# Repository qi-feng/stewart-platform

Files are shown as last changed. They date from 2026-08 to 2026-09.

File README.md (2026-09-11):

# Servo Stewart Platform

A student-buildable, 3D-printed rotary Stewart platform using six hobby servos, an Arduino Nano ESP32, and a PCA9685 servo driver. The project is being developed as a motion-control and optical-alignment test bed, with optional TTL-controlled laser, joystick, camera, Raspberry Pi, and reinforcement-learning extensions.

This repository is a fork of [Nathan Ge's Stewart platform](https://github.com/nzge/stewart-platform). The mechanical design has been adapted for DS3225 servos and expanded with electronics holders, a laser mount, and camera/Pi mounting parts. This repo contains ChatGPT code and stl files; this README is also made with the help of ChatGPT.

> **Project status:** The current interactive firmware is suitable for serial control of the servos and the platform orientation, as well as manual motion demonstration. Its X/Y and roll/pitch commands are still preliminary - not yet geometrically decoupled six-degree-of-freedom inverse kinematics. The range of motion can be limited until the geometry, servo centers, directions, and mechanical limits have been calibrated. 

## Demonstration video

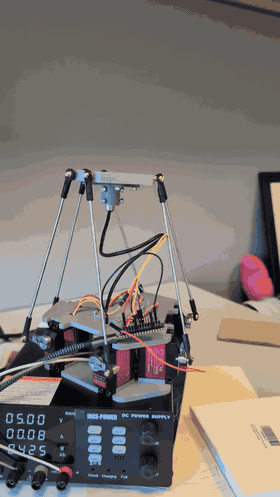
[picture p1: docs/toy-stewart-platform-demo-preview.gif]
Stewart platform demonstration


## Repository links

- [Revision 4 printable parts](https://github.com/qi-feng/stewart-platform/tree/main/cad/stewart-frame_rev4)
- [Arduino Stewart-platform controller](https://github.com/qi-feng/stewart-platform/blob/main/code/arduino-code/stewart_interactive_controller.ino)
- [Inverse-kinematics notebook](https://github.com/qi-feng/stewart-platform/blob/main/stewart_inverse-kinematics.ipynb)
- [Original Nathan Ge project](https://nzge.github.io/projects/stewart-platform.html)

## System overview

The Arduino Nano ESP32 sends I²C commands to the PCA9685. The PCA9685 generates six servo-control signals, while a separate regulated 5–6 V supply powers the servos. The joystick and USB/Wi-Fi console provide manual control. The Raspberry Pi, camera, and laser are optional and are not required for basic platform operation.

## Parts list

### Core electronics

| Qty | Part | Specification or example |
|---:|---|---|
| 6 | Positional digital servos | DS3225 (or similar), 25 kg class, 180° version—not continuous rotation |
| 1 | Microcontroller | [Arduino Nano ESP32 with headers, ABX00083](https://docs.arduino.cc/hardware/nano-esp32/) |
| 1 | Servo driver | [PCA9685 16-channel servo controller](https://www.amazon.com/dp/B07BRS249H) |
| 1 | Servo power supply | Regulated 5–6 V DC supply sized for the combined servo load; adjustable current limiting is useful during commissioning |
| 1 | Master power switch or emergency disconnect | Rated for the supply voltage and expected current |
| 1 | Inline fuse and holder | Select the fuse from the finished system's measured wiring and load requirements; do not automatically copy a 20 A value |
| 1 | Analog joystick with pushbutton | Two analog axes plus an active-low switch |
| 1 | USB-C data cable | For programming and initial Nano power |
| — | Logic and servo-power wiring | 20/22/24 AWG stranded wire or secure pre-crimped connectors |

### Mechanical parts

| Qty | Part | Specification or notes |
|---:|---|---|
| 6 | Aluminum clamping servo horns | 25T spline; approximately 25 mm servo-axis-to-ball-center radius in this build |
| 6 | M3 threaded linkage rods | Cut or adjust to the measured platform geometry |
| 12 | M3 ball-joint rod ends | Two per linkage; RC steering-linkage style |
| 12 | M3 jam nuts | One at each rod end to lock the adjusted linkage length |
| As needed | M3/M4 screws, washers, and nuts | Securing electronics, linkage hardware, and printed parts |
| As needed | M3/M4 heat-set inserts | For printed parts to mount the boards or the linkage rods |
| 1 set | 3D-printed structural parts | Base, base cover, upper platform/adapter, servo links, controller holder, and cover |
| 1 | Filament | PLA is suitable for initial builds; PETG can be used where greater toughness or heat resistance is useful |

All six completed linkages should begin with the same effective ball-center-to-ball-center length. The current prototype measurement is approximately **154 mm**, but builders must measure their own printed geometry rather than treating that value as universal.

### Optional optical and vision system

| Qty | Part | Specification or example |
|---:|---|---|
| 1 | TTL-controlled dot laser | 10 mm diameter × 40 mm length module used by this prototype |
| 1 | Printed laser mounts | Laser holder, camera case, camera stand, and Pi tray from the CAD directories |
| 1 | Camera | Arducam OV5647 5 MP camera with a Raspberry Pi or Xiao eps32s3-sense camera module or similar |
| 1 | Beam stop/enclosure | Non-reflective, mechanically secured, and appropriate for the selected laser class |

The laser and vision hardware are not needed for the initial servo build. Add them only after the platform homes reliably and its mechanical limits have been established.

## Wiring

Arduino Nano ESP32 to PCA9685 wiring

| Source pin | PCA9685 pin |
|---|---|
| Nano **3V3** | **VCC** |
| Nano **GND** | Logic-header **GND** |
| Nano **A4 / D21 / GPIO11** | **SDA** |
| Nano **A5 / D22 / GPIO12** | **SCL** |
| Servo supply **positive** | Screw-terminal **V+** |
| Servo supply **negative / 0 V** | Screw-terminal **GND** |
| Servo 0 three-wire plug | **CH0:** PWM/S, V+, GND |
| Servo 1 three-wire plug | **CH1:** PWM/S, V+, GND |
| Servo 2 three-wire plug | **CH2:** PWM/S, V+, GND |
| Servo 3 three-wire plug | **CH3:** PWM/S, V+, GND |
| Servo 4 three-wire plug | **CH4:** PWM/S, V+, GND |
| Servo 5 three-wire plug | **CH5:** PWM/S, V+, GND |
| PCA9685 **OE** | Leave unconnected for the basic build |

For each servo plug, connect its signal lead—usually orange, yellow, or white—to `PWM/S`; red to `V+`; and brown or black to `GND`. Follow the labels printed on the PCA9685 rather than assuming the physical row order is identical on every clone.

### Joystick wiring

| Joystick pin | Current project connection |
|---|---|
| VCC | PCA9685 **VCC** header—the same 3.3 V logic rail as Nano **3V3** |
| GND | PCA9685 logic-header **GND**—the common system ground |
| VRx | Nano **A0 / D17 / GPIO1** |
| VRy | Nano **A1 / D18 / GPIO2** |
| SW | Nano **D2 / GPIO5** |

### Current Quarton TTL-laser wiring

| Laser connection | Current project connection |
|---|---|
| Power / V+ | PCA9685 **V+** rail, supplied by the regulated **5 V** servo supply |
| Ground | PCA9685 **GND** / common system ground |
| TTL / EN | Nano **D7 / GPIO10** |

The sketch drives D7 **HIGH** to turn the laser on and **LOW** to turn it off. D7 is only the TTL control signal; it does not power the laser. This mapping is for the prototype's [Quarton VLM-520-61](https://www.quarton.com/green-circular-dot-laser-module-with-ttl-modulation-function-vlm-520-61-series.html) or [VLM-635-61](https://www.quarton.com/red-circular-dot-laser-module-with-ttl-modulation-function-vlm-635-61-series.html), which accept 3–6 V DC power. Verify the manufacturer's pinout rather than relying on wire color, especially when substituting a different module.

### Critical power rules

- `VCC` and `V+` are different. PCA9685 `VCC` receives 3.3 V logic power; `V+` receives the separate 5–6 V servo supply.
- Never power the six servos from the Nano's `3V3`, `VUSB`, or `VIN` pins.
- The Nano, PCA9685, servo supply, joystick, and optional laser-control circuit must share ground.
- Switch servo power off before changing wiring or installing servo horns.
- A breadboard may be used for low-current logic signals, but not for distributing servo power.

## Software setup

1. Install the [Arduino IDE](https://www.arduino.cc/en/software).
2. Install **Arduino ESP32 Boards by Arduino** using Boards Manager.
3. Select **Arduino Nano ESP32**.
4. Install **Adafruit PWM Servo Driver Library** using Library Manager.
5. Open the [Stewart-platform sketch](https://github.com/qi-feng/stewart-platform/blob/main/code/arduino-code/stewart_interactive_controller.ino).
6. Confirm the configured pins, servo directions, servo centers, and pulse limits before applying servo power.
7. Upload through USB-C and open Serial Monitor at **115200 baud**.

If the Wi-Fi-console version of the sketch is used, register the Nano's Wi-Fi MAC address, enter credentials locally without committing them to Git, and connect to the reported address with:

```bash
nc NANO_IP_ADDRESS 2323
```

## First power-on

1. Leave the servo horns disconnected from the linkages.
2. Confirm all six servos are positional 180° models.
3. Power the Nano over USB and verify that the PCA9685 responds at I²C address `0x40`.
4. Set the external servo supply to 5 V and a conservative current limit.
5. Connect and center one servo at a time.
6. Install each 25T horn at its intended neutral orientation while the servo is commanded to center.
7. Disconnect servo power and assemble the linkages.
8. Reapply power with one hand ready at the master disconnect.
9. Test HOME and small roll/pitch commands before selecting larger ranges or running the demonstration.

## Controls

The exact controls depend on the sketch revision. The current interactive development controller uses:

| Input | Action |
|---|---|
| Joystick X/Y | Accumulated roll and pitch control |
| Short joystick click | Toggle laser |
| Hold joystick button for 1 second | Smooth return to HOME |
| `h` | Return to HOME |
| `s` | Report current pulse-space pose and limits |
| `k` | Toggle laser |
| `?` | Print the complete command menu |

## Calibration and limitations

The current control values are PWM pulse offsets in microseconds; they are not millimeters or degrees. Before implementing true Cartesian motion, measure and record:

- Six base servo-axis coordinates and horn-rotation-axis directions
- Six upper-platform ball-joint coordinates
- Servo-axis-to-ball-center horn radius
- Effective ball-center-to-ball-center length of every linkage
- Individual servo direction, center pulse, minimum pulse, maximum pulse, and pulse-to-angle response
- Mechanical ball-joint and collision limits throughout the intended workspace

True inverse kinematics must solve each rotary horn angle from the requested platform translation and rotation. Until that solver is calibrated, X/Y motions may contain tilt and roll/pitch motions may contain translation.

## Laser safety

- Use the lowest-power visible laser that meets the experiment's needs.
- Enclose the beam path and terminate it with a fixed, non-reflective beam stop.
- Keep the beam below eye level and remove reflective objects from the enclosure.
- Turn the laser off during assembly, adjustment, and student access.
- Follow the institution's laser-safety rules and obtain approval from the responsible laboratory-safety office before classroom operation.

## Attribution and licensing

The starting mechanical design and repository structure came from [Nathan Ge's Stewart-platform project](https://github.com/nzge/stewart-platform). This fork contains subsequent experimental modifications and generated CAD/code artifacts.

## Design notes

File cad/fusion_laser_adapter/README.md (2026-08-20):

# Stewart-platform laser adapter generator

This Fusion 360 script modifies a selected solid copy of
`stewart-platform_adapter` and leaves the source assembly unchanged.

It creates:

- a 10.6 mm central laser passage;
- a 14 mm underside cable-relief pocket;
- a 30 mm OD × 4 mm reinforcing boss;
- a separate 10.4 mm-bore split collar for a 10 mm laser module.

## Run in Fusion

1. Open `stewart_assy.STEP` in Fusion's Design workspace.
2. Open **Utilities → Add-Ins → Scripts and Add-Ins**.
3. Select the **Scripts** tab and click the green **+** beside *My Scripts*.
4. Select the `fusion_laser_adapter` folder itself, not an individual `.py` file.
5. Run `fusion_laser_adapter`.
6. When prompted, select the solid body for `stewart-platform_adapter`.
7. Hide the original assembly and inspect the two new components.

The clamp is a first-fit collar intended for a small hose clamp or zip tie. Do
not print the full adapter until the center cut, rib reinforcement, cable relief,
and exact laser fit have been inspected in Fusion.

Fusion uses centimetres internally in its API; all user-facing dimensions above
are millimetres.

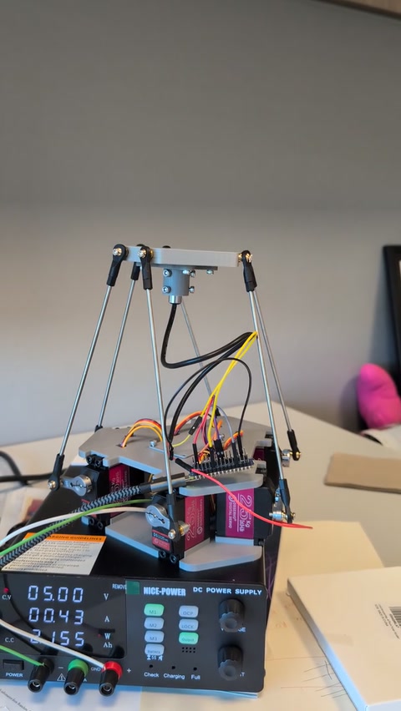
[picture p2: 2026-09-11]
docs/toy-stewart-platform-demo-poster.jpg

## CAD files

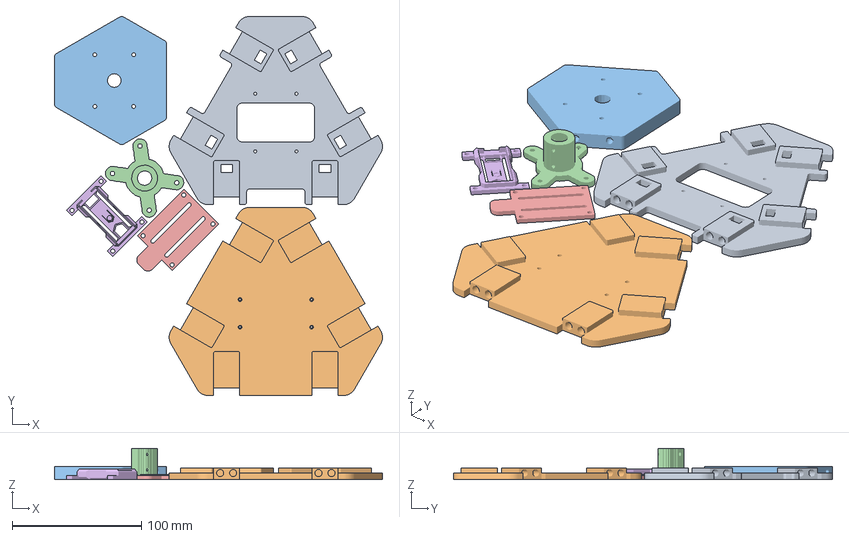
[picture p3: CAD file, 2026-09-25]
cad/stewart-frame_rev4/Stewart Platform.3mf
253.5 x 293.0 x 24.0 mm
base-cover_raised.STL
base_raised.STL
stewart-platform_adapter_laser_hole_centered.stl
laser_holder_10mm_six_screw_finder_40x30.stl
proto-board_nano-esp32_thick_slots_m3_usbc_support.stl
AN_top_cover_nano_esp32_m3_supported_bottom_mount_usb_flush.stl

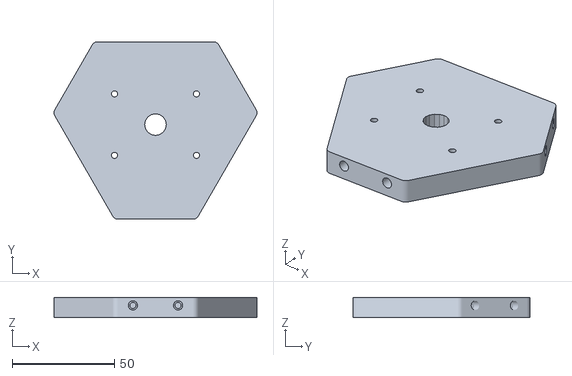
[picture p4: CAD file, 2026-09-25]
cad/stewart-frame_rev4/stewart-platform_adapter_laser_hole_centered.stl
99.1 x 86.6 x 10.0

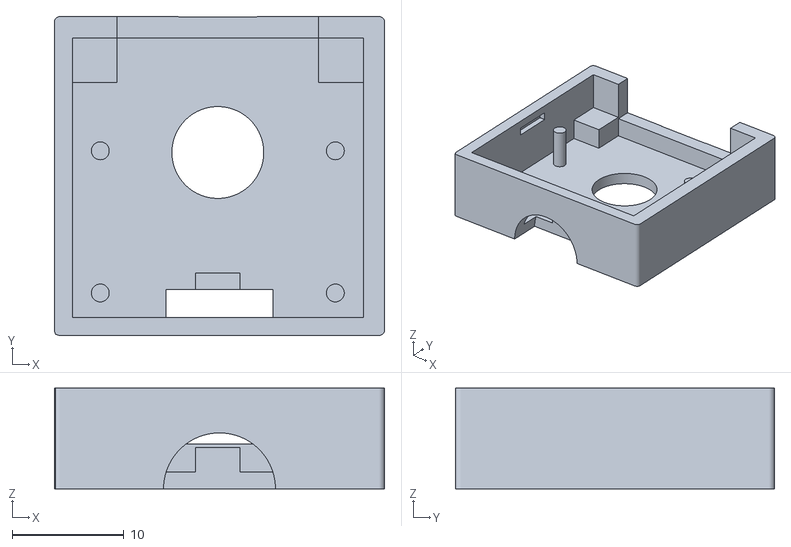
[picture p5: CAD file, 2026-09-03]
cad/stewart-frame_rev4/Arducam_OV5647_front_noear_opposite_pry_notch.stl
29.5 x 28.5 x 9.00

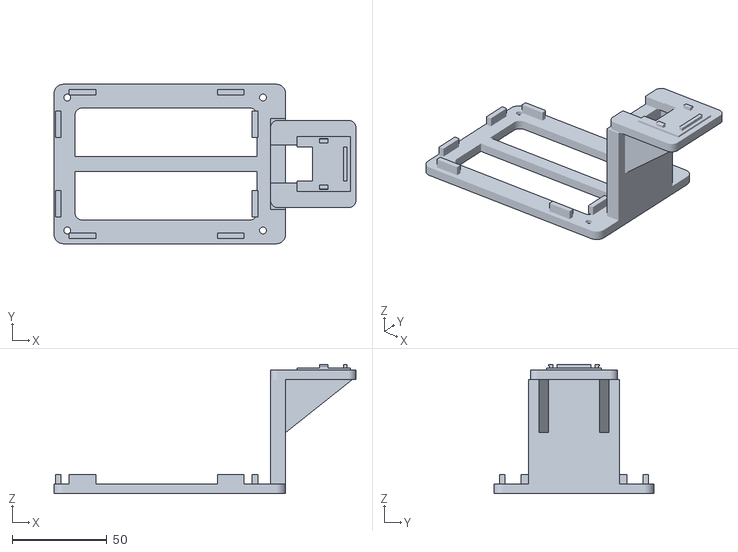
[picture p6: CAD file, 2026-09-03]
cad/stewart-frame_rev4/pi5_ov5647_split_02_pi_tray_camera_tower.stl
159.0 x 84.0 x 68.1

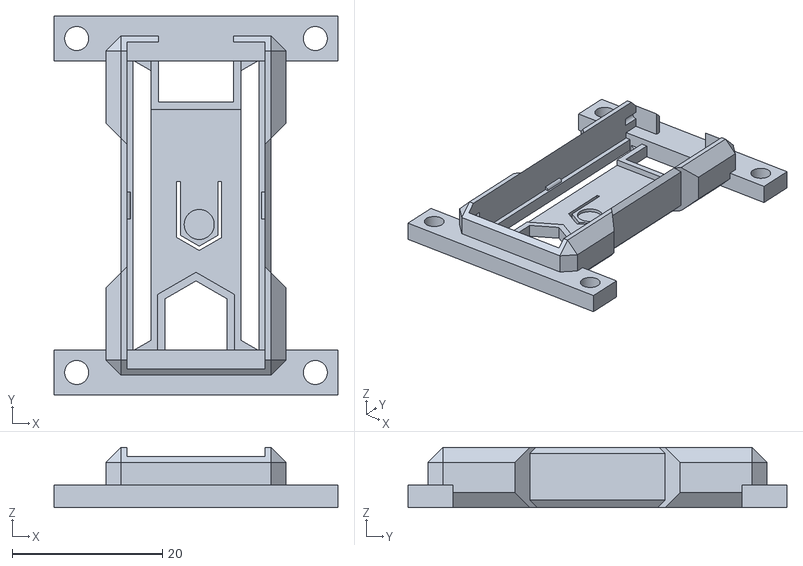
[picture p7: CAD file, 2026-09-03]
cad/stewart-frame_rev4/AN_top_cover_nano_esp32_m3_supported_bottom_mount_usb_flush.stl
37.8 x 50.5 x 8.00

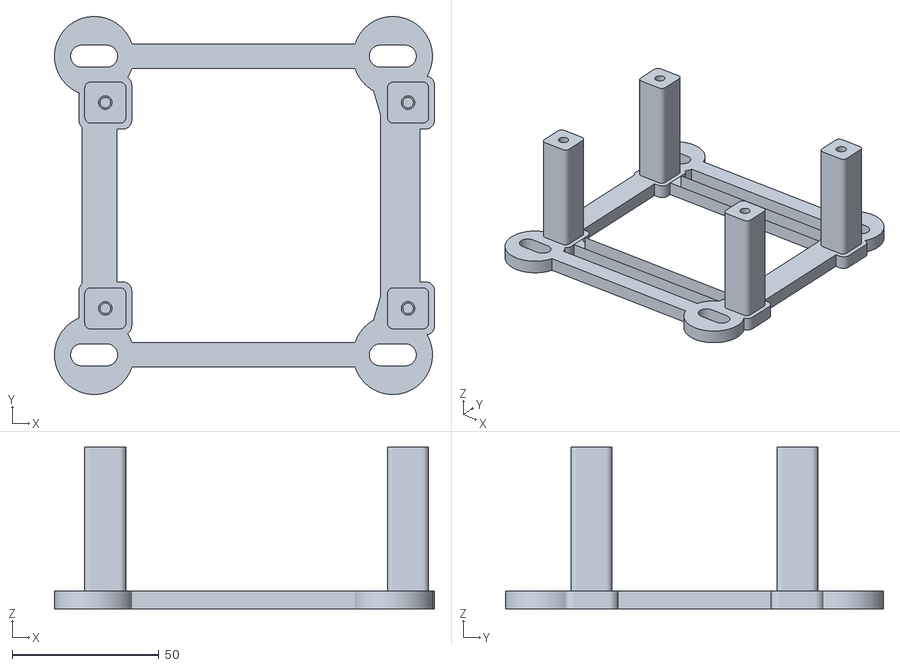
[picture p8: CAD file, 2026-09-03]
cad/stewart-frame_rev4/pi5_ov5647_split_01_optical_base_legs.stl
129.3 x 128.6 x 55.0

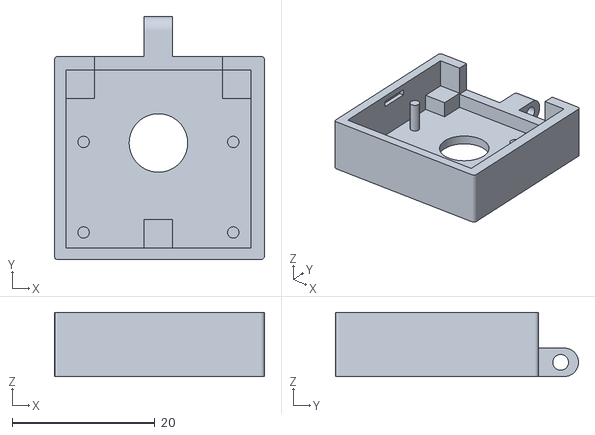
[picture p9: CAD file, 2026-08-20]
cad/stewart-frame_rev4/Arducam_OV5647_front-onepin.stl
29.5 x 34.1 x 9.00

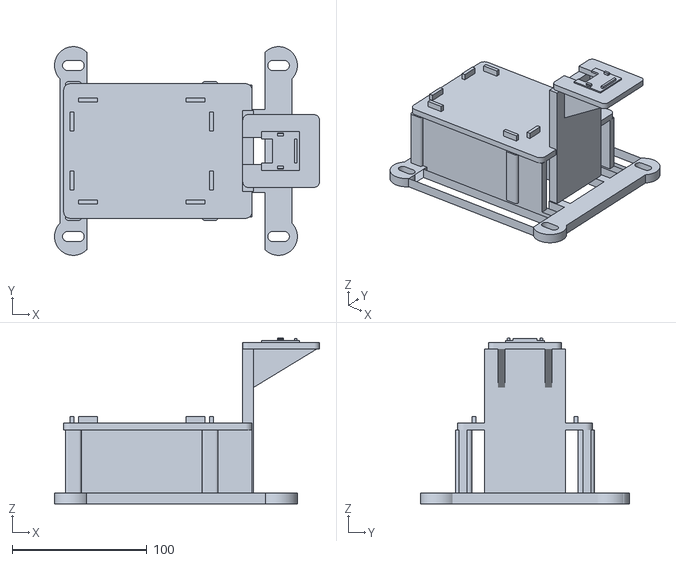
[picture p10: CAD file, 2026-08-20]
cad/stewart-frame_rev4/pi5_60mm_ov5647_120mm_optical_stand_back_ribbon_slot.stl
196.8 x 155.0 x 123.1

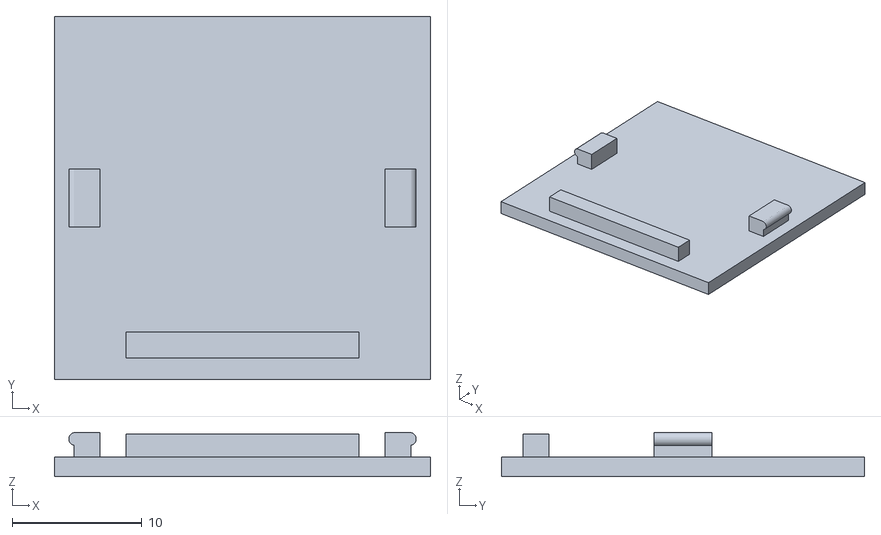
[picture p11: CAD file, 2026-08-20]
cad/stewart-frame_rev4/Arducam_OV5647_back.stl
29.0 x 28.0 x 3.40

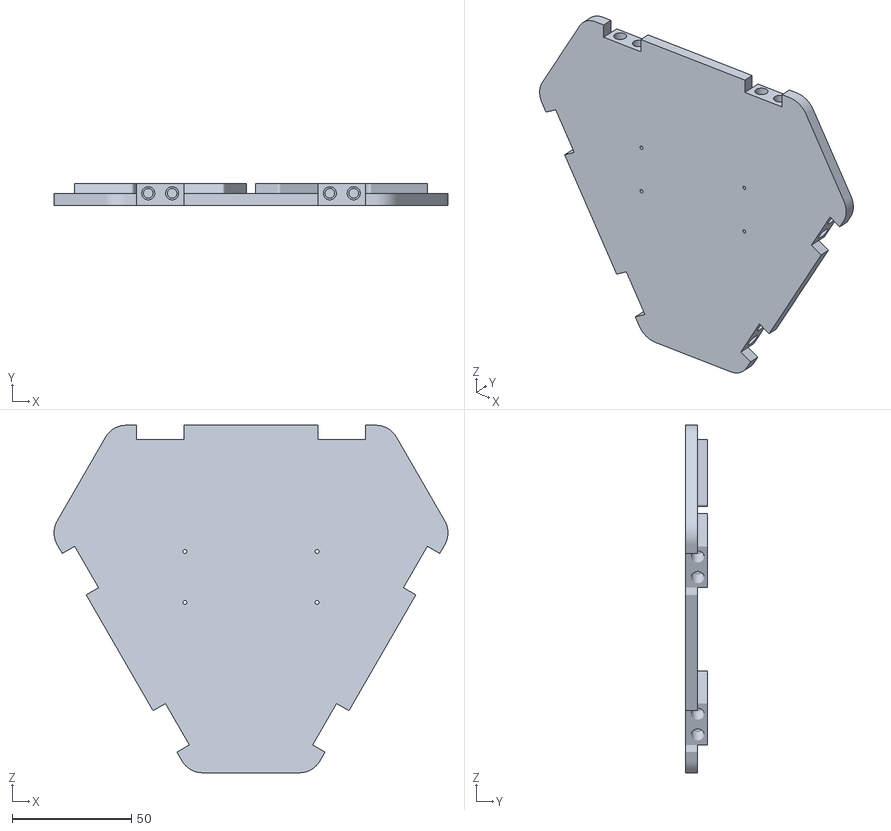
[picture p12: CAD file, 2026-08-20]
cad/stewart-frame_rev4/base_raised.STL
164.9 x 9.00 x 145.5

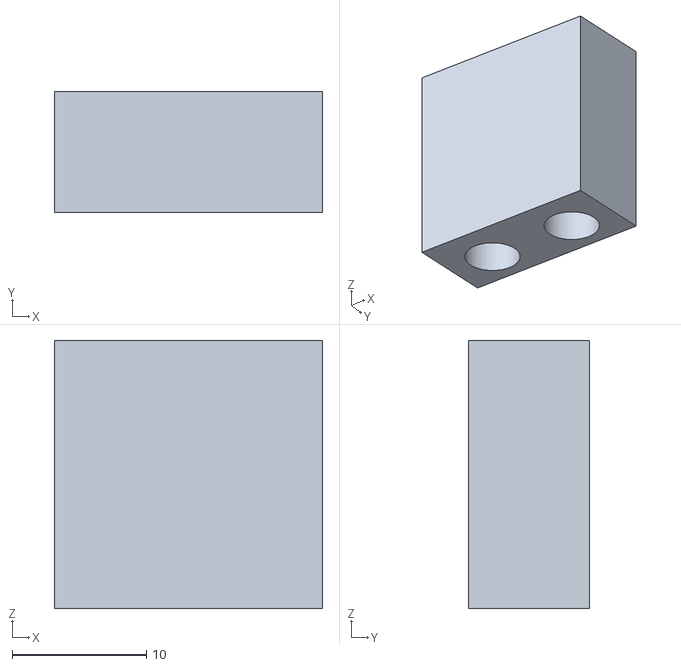
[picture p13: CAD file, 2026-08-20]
cad/stewart-frame_rev4/m4 heat insert test.STL
20.0 x 9.00 x 20.0

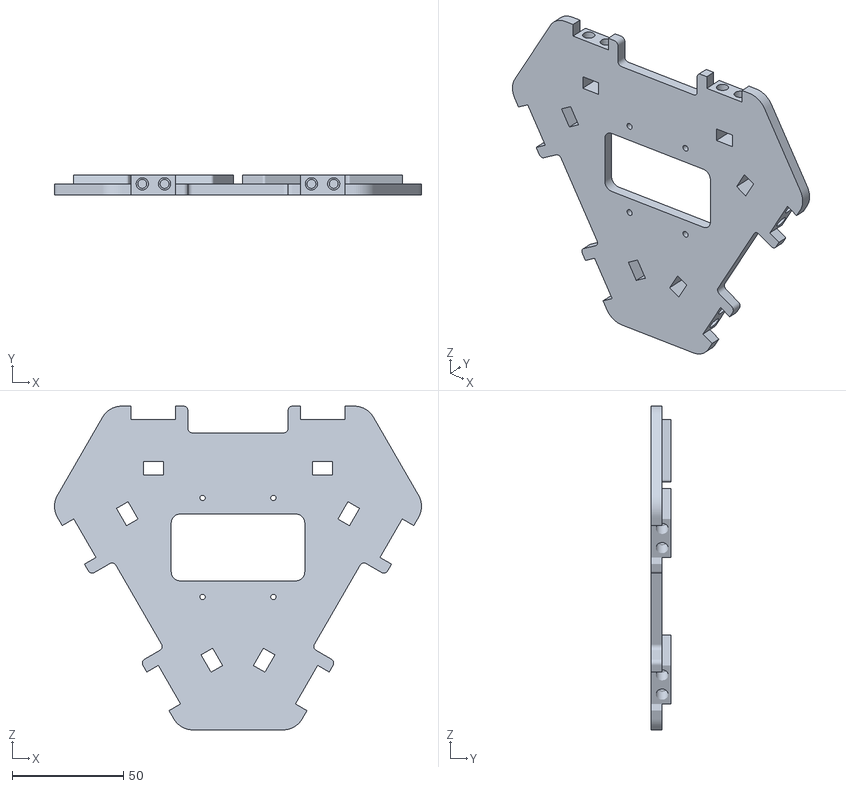
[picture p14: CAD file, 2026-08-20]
cad/stewart-frame_rev4/base-cover_raised.STL
164.9 x 9.00 x 145.5

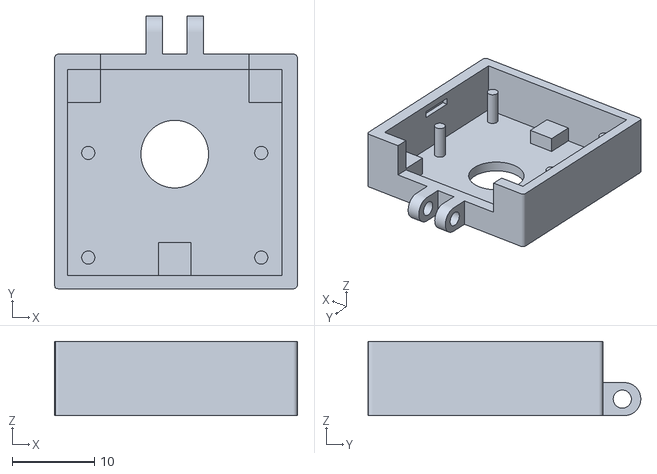
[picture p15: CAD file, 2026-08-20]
cad/stewart-frame_rev4/Arducam_OV5647_front.stl
29.5 x 33.1 x 9.00

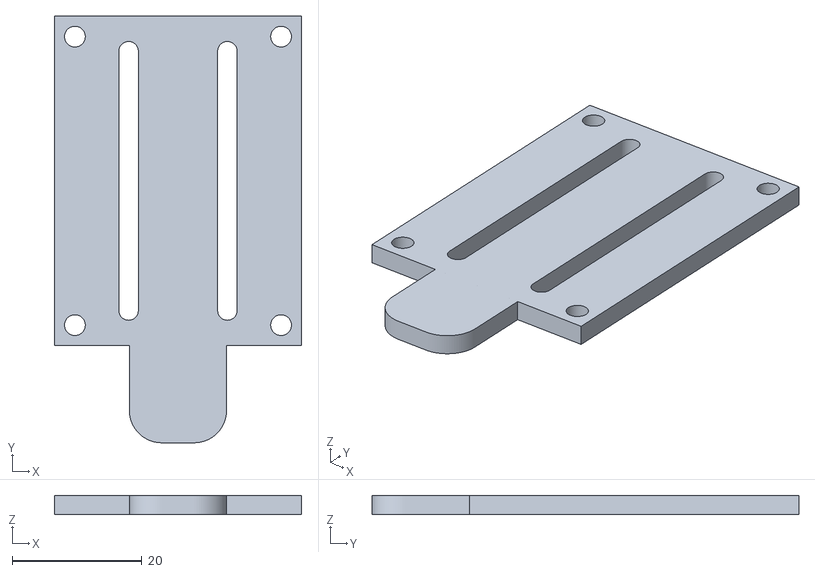
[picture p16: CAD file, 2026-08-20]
cad/stewart-frame_rev4/proto-board_nano-esp32_thick_slots_m3_usbc_support.stl
38.1 x 65.8 x 3.00

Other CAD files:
cad/stewart-frame_rev4/stewart-platform_adapter.STL
cad/stewart-frame_rev4/AN_top_cover_nano_esp32_m3_supported_bottom_mount.stl
cad/stewart-frame_rev4/laser_holder_10mm_six_screw_finder_40x30.stl
cad/stewart-frame_rev3/standoff.stl
cad/stewart-frame_rev3/AN_top_cover_nano_esp32_m3_mounting_legs.stl
cad/stewart-frame_rev3/AN_top_cover_nano_esp32_m3_supported_bottom_mount.stl
cad/stewart-frame_rev3/AN_top_cover_nano_esp32_m3_supported_top_mount.stl
cad/stewart-frame_rev3/C_Mount_Camera_Case_Back.stl
cad/stewart-frame_rev3/C_Mount_Camera_Case_Back_OV5647_4pin_1p35mm.stl
cad/stewart-frame_rev3/C_Mount_Camera_Case_Front.stl
cad/stewart-frame_rev3/C_Mount_Camera_Case_Front_Revison_A.stl
cad/stewart-frame_rev3/MORS.24.001.02 _ AN Top cover.stl
cad/stewart-frame_rev3/laser_holder_10mm_flanged_split.stl
cad/stewart-frame_rev3/laser_holder_10mm_m3_pinch_3point_adjustable_40x30.stl
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

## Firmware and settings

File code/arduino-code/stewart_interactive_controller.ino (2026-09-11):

// This sketch is written with the help of ChatGPT

#include <Wire.h>
#include <Adafruit_PWMServoDriver.h>
#include <math.h>
#include <WiFi.h>

Adafruit_PWMServoDriver pca9685(0x40);

constexpr uint8_t SERVO_COUNT = 6;
constexpr uint8_t LASER_PIN = D7;
constexpr uint8_t JOYSTICK_X_PIN = A0;
constexpr uint8_t JOYSTICK_Y_PIN = A1;
constexpr uint8_t JOYSTICK_BUTTON_PIN = D2;
constexpr float PCA_FREQUENCY = 50.0f;
constexpr unsigned long MOVE_MS = 180;    // Smooth response time per key press

// Joystick tuning for the Nano ESP32's 12-bit ADC (nominally 0-4095).
// Holding the stick farther from center produces faster accumulated motion.
constexpr int JOYSTICK_ADC_MAX = 4095;
constexpr int JOYSTICK_DEAD_ZONE = 180;
constexpr float JOYSTICK_MAX_RATE_US_PER_SECOND = 300.0f;
constexpr unsigned long JOYSTICK_UPDATE_MS = 40;
constexpr unsigned long BUTTON_DEBOUNCE_MS = 35;
constexpr unsigned long BUTTON_HOME_HOLD_MS = 1000;
constexpr unsigned long JOYSTICK_HOME_MOVE_MS = 600;
constexpr uint16_t WIFI_CONSOLE_PORT = 2323;
constexpr unsigned long WIFI_RETRY_MS = 15000;

// Replace only the password value before uploading. Keeping the Wi-Fi
// connection in this main sketch makes it reconnect after every restart.
const char* WIFI_SSID = "ULink";
const char* WIFI_PASSWORD = "xxxx";

WiFiServer consoleServer(WIFI_CONSOLE_PORT);
WiFiClient wifiConsole;
bool wifiServerStarted = false;
unsigned long lastWiFiAttemptMs = 0;

// Send status text to USB Serial and to the connected wireless console.
class TeeConsole : public Print {
 public:
  size_t write(uint8_t value) override {
    size_t written = Serial.write(value);
    if (wifiConsole && wifiConsole.connected()) {
      wifiConsole.write(value);
    }
    return written;
  }

  size_t write(const uint8_t* buffer, size_t size) override {
    size_t written = Serial.write(buffer, size);
    if (wifiConsole && wifiConsole.connected()) {
      wifiConsole.write(buffer, size);
    }
    return written;
  }
};

TeeConsole Console;

// Change either flag if an axis moves opposite to the direction you prefer.
constexpr bool REVERSE_JOYSTICK_ROLL = false;
constexpr bool REVERSE_JOYSTICK_PITCH = true;

// Runtime-adjustable control settings. Start in step gear 5 and range gear 8.
// Keys 1-5 and 6-9 can still change these settings after startup.
float stepUs = 100.0f;
float poseLimitUs = 700.0f;
float combinedLimitUs = 950.0f;

const uint8_t servoChannel[SERVO_COUNT] = {0, 1, 2, 3, 4, 5};

// Change an entry if that installed servo moves opposite to the desired motion.
int8_t servoDirection[SERVO_COUNT] = {+1, -1, +1, -1, +1, -1};

uint16_t servoCenterUs[SERVO_COUNT] = {1500, 1500, 1500, 1500, 1500, 1500};
// Wide hard limits for a nominal 500-2500 us / 180-degree DS3225. The 50 us
// endpoint margin avoids deliberately driving against the mechanical stops.
uint16_t servoMinUs[SERVO_COUNT] = {550, 550, 550, 550, 550, 550};
uint16_t servoMaxUs[SERVO_COUNT] = {2450, 2450, 2450, 2450, 2450, 2450};

float currentPulseUs[SERVO_COUNT] = {1500, 1500, 1500, 1500, 1500, 1500};

// Servo positions viewed from above:
//
//                 BACK
//              3       4
//          2               5
//              1       0
//                 FRONT
const float servoX[SERVO_COUNT] = {0.5, -0.5, -1.0, -0.5, 0.5, 1.0};
const float servoY[SERVO_COUNT] = {-0.866, -0.866, 0.0, 0.866, 0.866, 0.0};

// Preliminary alternating-leg yaw pattern. This is only a diagnostic until
// the real base/platform joint coordinates and horn geometry are calibrated.
const float servoYaw[SERVO_COUNT] = {1.0, -1.0, 1.0, -1.0, 1.0, -1.0};

// Persistent "game" controls. Repeated key presses accumulate here.
float poseX = 0;
float poseY = 0;
float poseZ = 0;
float poseRoll = 0;
float posePitch = 0;
float poseYaw = 0;
bool laserIsOn = false;

int joystickCenterX = JOYSTICK_ADC_MAX / 2;
int joystickCenterY = JOYSTICK_ADC_MAX / 2;
unsigned long lastJoystickUpdateMs = 0;
bool lastButtonReading = HIGH;
bool stableButtonState = HIGH;
unsigned long lastButtonChangeMs = 0;
unsigned long buttonPressedMs = 0;
bool longPressHandled = false;
bool homeRequested = false;

void updateJoystickButton();
void homePlatform(unsigned long durationMs = MOVE_MS);
void handleCommand(char command);
void printPose();
void printMenu();

void beginWiFiAttempt() {
  WiFi.begin(WIFI_SSID, WIFI_PASSWORD);
  lastWiFiAttemptMs = millis();
  Console.println("Connecting to Wi-Fi in background...");
}

void startWiFiConsole() {
  WiFi.mode(WIFI_STA);
  WiFi.setSleep(false);
  Console.print("Nano ESP32 Wi-Fi MAC: ");
  Console.println(WiFi.macAddress());
  beginWiFiAttempt();
}

void serviceWiFiConsole() {
  if (WiFi.status() != WL_CONNECTED) {
    if (wifiConsole) wifiConsole.stop();
    wifiServerStarted = false;

    if (millis() - lastWiFiAttemptMs >= WIFI_RETRY_MS) {
      WiFi.disconnect();
      beginWiFiAttempt();
    }
    return;
  }

  if (!wifiServerStarted) {
    consoleServer.begin();
    wifiServerStarted = true;
    Console.print("Wi-Fi console ready at ");
    Console.print(WiFi.localIP());
    Console.print(":");
    Console.println(WIFI_CONSOLE_PORT);
  }

  if (!wifiConsole || !wifiConsole.connected()) {
    WiFiClient newClient = consoleServer.available();
    if (newClient) {
      wifiConsole.stop();
      wifiConsole = newClient;
      wifiConsole.setNoDelay(true);
      Console.println("Wireless console connected.");
      printPose();
      printMenu();
    }
  }

  while (wifiConsole && wifiConsole.connected() && wifiConsole.available()) {
    handleCommand((char)wifiConsole.read());
  }
}

void setLaser(bool turnOn) {
  laserIsOn = turnOn;
  digitalWrite(LASER_PIN, laserIsOn ? HIGH : LOW);
  Console.print("Laser: ");
  Console.println(laserIsOn ? "ON" : "OFF");
}

void toggleLaser() {
  setLaser(!laserIsOn);
}

float clampValue(float value, float low, float high) {
  if (value < low) return low;
  if (value > high) return high;
  return value;
}

uint16_t constrainPulse(uint8_t servo, float pulseUs) {
  return (uint16_t)round(clampValue(pulseUs, servoMinUs[servo], servoMaxUs[servo]));
}

void writeServoPulse(uint8_t servo, float pulseUs) {
  uint16_t safePulse = constrainPulse(servo, pulseUs);
  pca9685.writeMicroseconds(servoChannel[servo], safePulse);
  currentPulseUs[servo] = safePulse;
}

void moveToLogicalOffsets(const float requested[SERVO_COUNT], unsigned long durationMs) {
  float startPulse[SERVO_COUNT];
  float endPulse[SERVO_COUNT];
  float largest = 0;

  for (uint8_t i = 0; i < SERVO_COUNT; i++) {
    largest = max(largest, fabs(requested[i]));
  }

  // Preserve the requested shape while scaling it into the safe envelope.
  float scale = largest > combinedLimitUs ? combinedLimitUs / largest : 1.0f;

  for (uint8_t i = 0; i < SERVO_COUNT; i++) {
    startPulse[i] = currentPulseUs[i];
    float logicalOffset = requested[i] * scale;
    endPulse[i] = servoCenterUs[i] + servoDirection[i] * logicalOffset;
  }

  constexpr unsigned long UPDATE_MS = 20;
  unsigned long steps = max(1UL, durationMs / UPDATE_MS);

  for (unsigned long step = 1; step <= steps; step++) {
    float fraction = (float)step / (float)steps;
    float smooth = fraction * fraction * (3.0f - 2.0f * fraction);

    for (uint8_t servo = 0; servo < SERVO_COUNT; servo++) {
      float pulse = startPulse[servo] + (endPulse[servo] - startPulse[servo]) * smooth;
      writeServoPulse(servo, pulse);
    }
    // The older motion code is blocking, so explicitly service the click here.
    updateJoystickButton();
    delay(UPDATE_MS);
  }
}

void applyPose(unsigned long durationMs = MOVE_MS) {
  float offsets[SERVO_COUNT];

  for (uint8_t i = 0; i < SERVO_COUNT; i++) {
    // X/Y are diagnostic sway controls, not true Cartesian translations.
    // Roll/pitch use the same simple geometric weighting from the test sketch.
    offsets[i] = poseZ
               + poseX * servoX[i]
               + poseY * servoY[i]
               + poseRoll * servoX[i]
               + posePitch * servoY[i]
               + poseYaw * servoYaw[i];
  }

  moveToLogicalOffsets(offsets, durationMs);
}

void calibrateJoystickCenter() {
  constexpr uint8_t SAMPLE_COUNT = 32;
  long sumX = 0;
  long sumY = 0;

  Console.println("Release joystick and keep it centered: calibrating...");
  delay(300);
  for (uint8_t sample = 0; sample < SAMPLE_COUNT; sample++) {
    sumX += analogRead(JOYSTICK_X_PIN);
    sumY += analogRead(JOYSTICK_Y_PIN);
    delay(5);
  }

  joystickCenterX = sumX / SAMPLE_COUNT;
  joystickCenterY = sumY / SAMPLE_COUNT;
  lastJoystickUpdateMs = millis();

  Console.print("Joystick center: X=");
  Console.print(joystickCenterX);
  Console.print(" Y=");
  Console.println(joystickCenterY);
}

// Convert an ADC reading into a signed -1..+1 velocity command. Squaring the
// magnitude provides fine control near center while retaining full speed.
float joystickVelocity(int reading, int center, bool reverseAxis) {
  int offset = reading - center;
  int magnitude = abs(offset);
  if (magnitude <= JOYSTICK_DEAD_ZONE) return 0.0f;

  int availableRange = offset >= 0
                     ? JOYSTICK_ADC_MAX - center
                     : center;
  availableRange = max(availableRange, JOYSTICK_DEAD_ZONE + 1);

  float normalized = (float)(magnitude - JOYSTICK_DEAD_ZONE)
                   / (float)(availableRange - JOYSTICK_DEAD_ZONE);
  normalized = clampValue(normalized, 0.0f, 1.0f);
  normalized *= normalized;

  float velocity = offset >= 0 ? normalized : -normalized;
  return reverseAxis ? -velocity : velocity;
}

void updateJoystickButton() {
  bool reading = digitalRead(JOYSTICK_BUTTON_PIN);
  unsigned long now = millis();

  if (reading != lastButtonReading) {
    lastButtonChangeMs = now;
    lastButtonReading = reading;
  }

  if ((now - lastButtonChangeMs) >= BUTTON_DEBOUNCE_MS
      && reading != stableButtonState) {
    stableButtonState = reading;
    if (stableButtonState == LOW) {
      buttonPressedMs = now;
      longPressHandled = false;
    } else if (!longPressHandled) {
      // A short click keeps its original laser-toggle behavior.
      toggleLaser();
    }
  }

  if (stableButtonState == LOW
      && !longPressHandled
      && (now - buttonPressedMs) >= BUTTON_HOME_HOLD_MS) {
    // Defer the actual move until updateJoystick() is at top level. This
    // avoids starting HOME from inside an already-running smooth servo move.
    longPressHandled = true;
    homeRequested = true;
  }
}

void printJoystickButtonState() {
  int state = digitalRead(JOYSTICK_BUTTON_PIN);
  Console.print("Joystick SW on D2 is ");
  Console.print(state == LOW ? "PRESSED" : "released");
  Console.print(" (raw=");
  Console.print(state);
  Console.println("; expected pressed=0, released=1)");
}

void updateJoystick() {
  updateJoystickButton();

  if (homeRequested) {
    homeRequested = false;
    homePlatform(JOYSTICK_HOME_MOVE_MS);
    lastJoystickUpdateMs = millis();
    return;
  }

  // Do not let a displaced stick move the platform away while its button is
  // being held for HOME.
  if (stableButtonState == LOW) {
    lastJoystickUpdateMs = millis();
    return;
  }

  unsigned long now = millis();
  unsigned long elapsedMs = now - lastJoystickUpdateMs;
  if (elapsedMs < JOYSTICK_UPDATE_MS) return;
  lastJoystickUpdateMs = now;

  float rollVelocity = joystickVelocity(
    analogRead(JOYSTICK_X_PIN), joystickCenterX, REVERSE_JOYSTICK_ROLL
  );
  float pitchVelocity = joystickVelocity(
    analogRead(JOYSTICK_Y_PIN), joystickCenterY, REVERSE_JOYSTICK_PITCH
  );

  if (rollVelocity == 0.0f && pitchVelocity == 0.0f) return;

  // Limit a long scheduling pause so it cannot produce one unexpectedly large move.
  float elapsedSeconds = min(elapsedMs, 100UL) / 1000.0f;
  poseRoll = clampValue(
    poseRoll + rollVelocity * JOYSTICK_MAX_RATE_US_PER_SECOND * elapsedSeconds,
    -poseLimitUs,
    poseLimitUs
  );
  posePitch = clampValue(
    posePitch + pitchVelocity * JOYSTICK_MAX_RATE_US_PER_SECOND * elapsedSeconds,
    -poseLimitUs,
    poseLimitUs
  );

  applyPose(JOYSTICK_UPDATE_MS);
}

void printPose() {
  Console.print("Pose  X="); Console.print(poseX, 0);
  Console.print("  Y="); Console.print(poseY, 0);
  Console.print("  Z="); Console.print(poseZ, 0);
  Console.print("  Roll="); Console.print(poseRoll, 0);
  Console.print("  Pitch="); Console.print(posePitch, 0);
  Console.print("  Yaw="); Console.print(poseYaw, 0);
  Console.print("  | step="); Console.print(stepUs, 0);
  Console.print("  axis range=+/-"); Console.print(poseLimitUs, 0);
  Console.print("  leg limit=+/-"); Console.println(combinedLimitUs, 0);
}

void changeControl(float &control, float amount) {
  control = clampValue(control + amount, -poseLimitUs, poseLimitUs);
  applyPose();
  printPose();
}

void setStep(float newStepUs) {
  stepUs = newStepUs;
  Console.print("Step size set to ");
  Console.print(stepUs, 0);
  Console.println(" us per key press");
}

void setRange(float newPoseLimitUs, float newCombinedLimitUs) {
  poseLimitUs = newPoseLimitUs;
  combinedLimitUs = newCombinedLimitUs;

  // Bring an already accumulated pose inside the newly selected envelope.
  poseX = clampValue(poseX, -poseLimitUs, poseLimitUs);
  poseY = clampValue(poseY, -poseLimitUs, poseLimitUs);
  poseZ = clampValue(poseZ, -poseLimitUs, poseLimitUs);
  poseRoll = clampValue(poseRoll, -poseLimitUs, poseLimitUs);
  posePitch = clampValue(posePitch, -poseLimitUs, poseLimitUs);
  poseYaw = clampValue(poseYaw, -poseLimitUs, poseLimitUs);
  applyPose();

  Console.print("Range set: each control +/-");
  Console.print(poseLimitUs, 0);
  Console.print(" us; combined servo limit +/-");
  Console.print(combinedLimitUs, 0);
  Console.println(" us");
}

void homePlatform(unsigned long durationMs) {
  poseX = poseY = poseZ = poseRoll = posePitch = poseYaw = 0;
  applyPose(durationMs);
  Console.println("HOME");
  printPose();
}

void demoPause() {
  unsigned long startMs = millis();
  while (millis() - startMs < 650) {
    updateJoystickButton();
    delay(5);
  }
}

void runMasterDemo() {
  // Keep this deliberately smaller than the selected interactive range.
  float amount = min(poseLimitUs, 120.0f);

  Console.println("MASTER DEMO START");
  Console.println("X/Y/yaw are diagnostic patterns until geometric calibration.");
  homePlatform();
  demoPause();

  Console.println("Z + / -");
  poseZ = amount; applyPose(); demoPause();
  poseZ = -amount; applyPose(); demoPause();
  homePlatform(); demoPause();

  Console.println("X sway + / - (translation and tilt are currently coupled)");
  poseX = amount; applyPose(); demoPause();
  poseX = -amount; applyPose(); demoPause();
  homePlatform(); demoPause();

  Console.println("Y sway + / - (translation and tilt are currently coupled)");
  poseY = amount; applyPose(); demoPause();
  poseY = -amount; applyPose(); demoPause();
  homePlatform(); demoPause();

  Console.println("Roll + / -");
  poseRoll = amount; applyPose(); demoPause();
  poseRoll = -amount; applyPose(); demoPause();
  homePlatform(); demoPause();

  Console.println("Pitch + / -");
  posePitch = amount; applyPose(); demoPause();
  posePitch = -amount; applyPose(); demoPause();
  homePlatform(); demoPause();

  Console.println("Yaw diagnostic + / -");
  poseYaw = amount * 0.6f; applyPose(); demoPause();
  poseYaw = -amount * 0.6f; applyPose(); demoPause();
  homePlatform();

  Console.println("MASTER DEMO COMPLETE; HOME");
}

void printMenu() {
  Console.println();
  Console.println("Interactive Stewart Platform");
  Console.println("Motion controls:");
  Console.println("  x / X : X sway + / -");
  Console.println("  y / Y : Y sway + / -");
  Console.println("  u / d : Z up / down");
  Console.println("  r / R : roll + / -");
  Console.println("  p / P : pitch + / -");
  Console.println("  a / A : yaw diagnostic + / -");
  Console.println("  h     : smooth return HOME");
  Console.println("  s     : show current pose, step size, and range");
  Console.println("  t     : master motion demonstration");
  Console.println("  l     : laser ON");
  Console.println("  L     : laser OFF");
  Console.println("  k     : toggle laser ON/OFF");
  Console.println("  j     : recalibrate joystick center (release stick first)");
  Console.println("  b     : report joystick button state for wiring diagnosis");
  Console.println("Joystick:");
  Console.println("  X axis: roll; Y axis: pitch; farther = faster");
  Console.println("  Short click: toggle laser ON/OFF");
  Console.println("  Hold 1 second: smooth return HOME");
  Console.println("  Release holds the current roll/pitch position");
  Console.println();
  Console.println("Step-size gears:");
  Console.println("  1=1 us, 2=10 us, 3=25 us, 4=50 us, 5=100 us");
  Console.println("Range gears (approximate; verify your own servo calibration):");
  Console.println("  6=+/-220 us  conservative");
  Console.println("  7=+/-450 us  medium");
  Console.println("  8=axis +/-700 us, combined leg +/-950 us  large");
  Console.println("  9=+/-900 us  near full nominal travel");
  Console.println("  ?     : show this menu");
  Console.println();
}

void handleCommand(char command) {
  switch (command) {
    case 'x': changeControl(poseX, +stepUs); break;
    case 'X': changeControl(poseX, -stepUs); break;
    case 'y': changeControl(poseY, +stepUs); break;
    case 'Y': changeControl(poseY, -stepUs); break;
    case 'u': changeControl(poseZ, +stepUs); break;
    case 'd': changeControl(poseZ, -stepUs); break;
    case 'r': changeControl(poseRoll, +stepUs); break;
    case 'R': changeControl(poseRoll, -stepUs); break;
    case 'p': changeControl(posePitch, +stepUs); break;
    case 'P': changeControl(posePitch, -stepUs); break;
    case 'a': changeControl(poseYaw, +stepUs); break;
    case 'A': changeControl(poseYaw, -stepUs); break;
    case 'h': homePlatform(); break;
    case 's': printPose(); break;
    case 't': runMasterDemo(); break;
    case 'l': setLaser(true); break;
    case 'L': setLaser(false); break;
    case 'k': toggleLaser(); break;
    case 'j': calibrateJoystickCenter(); break;
    case 'b': printJoystickButtonState(); break;
    case '1': setStep(1); break;
    case '2': setStep(10); break;
    case '3': setStep(25); break;
    case '4': setStep(50); break;
    case '5': setStep(100); break;
    case '6': setRange(220, 220); break;
    case '7': setRange(450, 450); break;
    case '8': setRange(700, 950); break;
    case '9': setRange(900, 900); break;
    case '?': printMenu(); break;
    case '\n':
    case '\r': break;
    default:
      Console.print("Unknown key: ");
      Console.println(command);
      break;
  }
}

void setup() {
  Serial.begin(115200);
  delay(1500);

  // Establish the safe state before initializing the servo controller.
  pinMode(LASER_PIN, OUTPUT);
  digitalWrite(LASER_PIN, LOW);
  laserIsOn = false;

  pinMode(JOYSTICK_BUTTON_PIN, INPUT_PULLUP);
  analogReadResolution(12);
  lastButtonReading = digitalRead(JOYSTICK_BUTTON_PIN);
  stableButtonState = lastButtonReading;

  Wire.begin(A4, A5);
  pca9685.begin();
  pca9685.setOscillatorFrequency(25000000);
  pca9685.setPWMFreq(PCA_FREQUENCY);
  delay(500);

  for (uint8_t servo = 0; servo < SERVO_COUNT; servo++) {
    currentPulseUs[servo] = servoCenterUs[servo];
    writeServoPulse(servo, servoCenterUs[servo]);
    delay(100);
  }

  Console.println("PCA9685 initialized; platform at HOME.");
  Console.println("Laser initialized OFF.");
  calibrateJoystickCenter();
  Console.println("Startup setting: step gear 5, range gear 8.");
  printPose();
  printMenu();

  // Wi-Fi starts only after the laser and servos have reached safe states.
  // Connection and retries happen in the background, so joystick and USB
  // controls remain available even when the network is down.
  startWiFiConsole();
}

void loop() {
  serviceWiFiConsole();
  updateJoystick();

  while (Serial.available()) {
    handleCommand((char)Serial.read());
  }
}

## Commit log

2026-08-20 Add Pi 5, camera, and laser platform modifications
    [AN_top_cover_nano_esp32_m3_mounting_legs.stl, AN_top_cover_nano_esp32_m3_supported_bottom_mount.stl, AN_top_cover_nano_esp32_m3_supported_top_mount.stl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]
2026-08-20 Add arduino sketch
2026-09-03 added stl files
    [AN_top_cover_nano_esp32_m3_supported_bottom_mount_usb_flush.stl, Arducam_OV5647_front_noear_opposite_pry_notch.stl, pi5_ov5647_split_01_optical_base_legs.stl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]
2026-09-11 updated SP arduino sketch with joystick control and serial command control and wifi capability
2026-09-11 added missing print file
    [stewart-platform_adapter.STL]
2026-09-11 Document joystick and TTL laser wiring
